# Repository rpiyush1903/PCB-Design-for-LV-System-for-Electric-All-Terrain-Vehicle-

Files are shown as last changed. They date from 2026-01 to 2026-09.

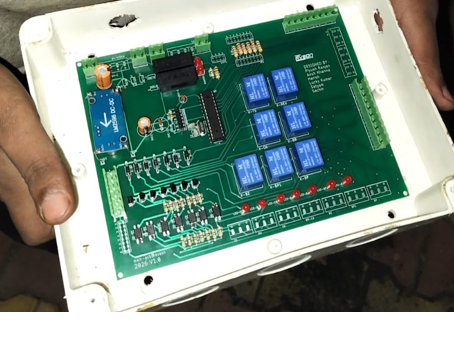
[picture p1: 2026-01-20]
LV-Control-Unit.png

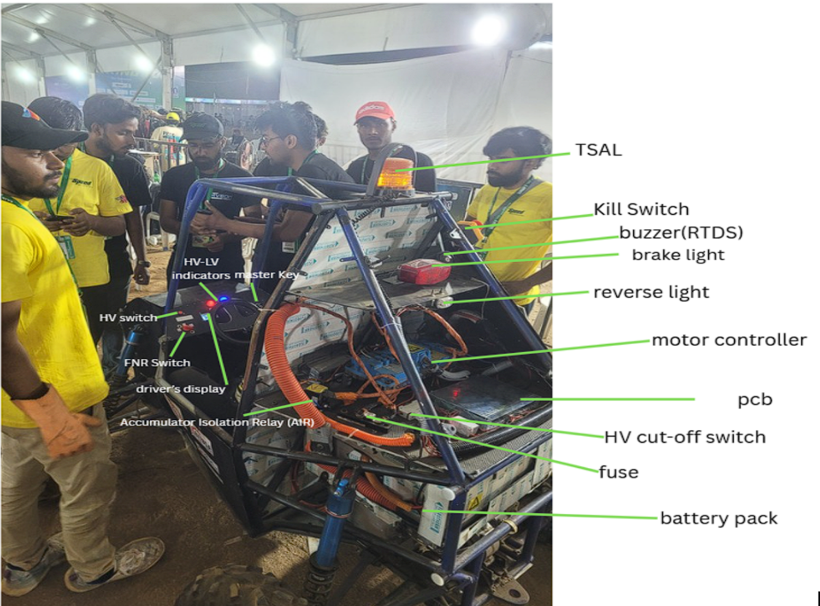
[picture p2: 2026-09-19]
e-atv.png

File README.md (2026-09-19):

# e-ATV Vehicle Control Unit (VCU)

## What this is

This is the Vehicle Control Unit (VCU) for our electric All-Terrain Vehicle, engineered specifically for the demands of e-BAJA SAE competition . The control unit should be resistant to high vibration, rough terrain, electrical noise etc.

The VCU sits at the center of the car's low-voltage control system. It reads every driver input ,ignition Key, cockpit and chassis kill switches, brake pressure switch, accelerator position sensor, and Forward/Neutral/Reverse selection(Rotary Switch) and turns that into safe, Low Voltage control over the high-voltage tractive system. It continuously monitors the safety loop, runs the basic starting and running logic of the vehicle , Controls all the Low Voltage and High Voltage components in the vehicle and is built to shut the whole tractive system down immediately if anything looks wrong.

## Hardware Design & PCB Architecture
The whole electrical layout is built with the idea of Simple , Efficient Control and Robust Safety 

The VCU PCB is made to protect the ATmega328P microcontroller from high-voltage transients, high-current switching noise, and off-road mechanical vibration through strategic domain isolation and multi-stage output driving.

## 1. Power Distribution & System Isolation

### 48V Tractive System
Powers the motor controller through a 160A main fuse, HV cut-off switch, and main Accumulator Isolation Relays (AIRs).

### 12V LV System
Stepped down via a 48V-to-12V DC-DC converter to power external safety loops, lights, RTDS buzzer, and relay coils.

### 5V Logic System
Generated by a dedicated 12V-to-5V buck converter with electrolytic (100 µF) and ceramic (0.1 µF) decoupling capacitors, providing clean power exclusively to the MCU and sensor pull-up networks.

## 2. Optocoupler & Active-LOW Output Drive

### Active-LOW Logic
GPIO output pins require  0V (LOW) signal to energize outputs. Floating pin states during bootloader execution or CPU resets cannot accidentally trigger relays.

### Galvanic Isolation
Output pins drive PC817 optocouplers, creating an optical barrier between the 5V MCU logic ground and the 12V relay ground plane.

### Low-Side Switching
Optocoupler phototransistors trigger BC547 NPN transistors to sink 12V relay coil current, keeping high current draw entirely off the 5V logic rail.

### Flyback Diode Clamping
1N4007 flyback diodes are placed in reversed manner and parallel across all relay coils to safely dissipate back-EMF inductive voltage spikes ($V = -L \frac{di}{dt}$) during de-energization, preventing CMOS latch-up.

### Digital Inputs
Brake pressure switch (A3), FNR selectors (A4/A5), and safety interlocks (A1) utilize pull-down resistor networks and hardware debouncing to guarantee stable state detection across rough terrain.

### Power Distribution

* **High Voltage Rail:** The 48V accumulator feeds through a 160A main fuse and an HV cut-off switch straight to the motor controller.
* **Low Voltage Rail:** A 48V→12V DC-DC converter powers the vehicle's 12V accessories and the dashboard safety loop.
* **Logic Power:** The ATmega328P and its supporting logic get their own dedicated 12V→5V buck converter, kept isolated from everything else on the low-voltage side.

### Core Components

* **MCU:** ATmega328P
* **Sensor Inputs:** Ignition key, cockpit and chassis kill switches, brake pressure switch, accelerator (Hall-effect sensor), and the Forward/Neutral/Reverse selector all fed from the dashboard cluster.
* **Actuator Outputs:** Relay-driven outputs for the TSAL, reverse light, main contactor (accumulator isolation relay), brake light, and the RTDS buzzer.

## Firmware Architecture

The firmware (C++, compiled through Arduino) is built with the starting sequence in mind and safety as a priority .

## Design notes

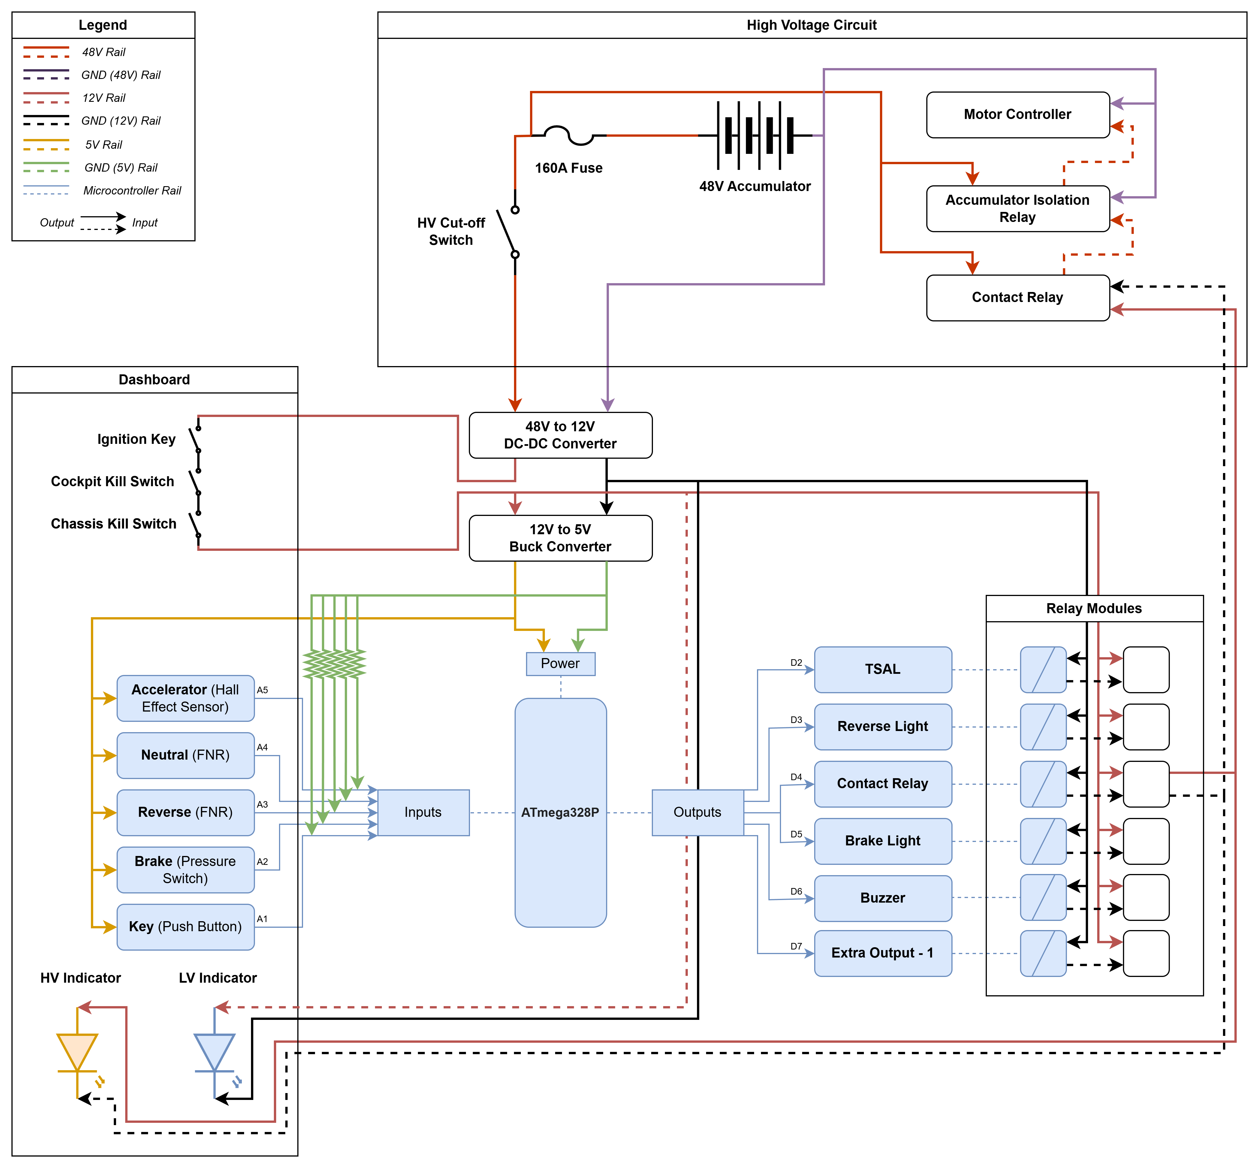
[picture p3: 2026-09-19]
LV-HV-System-Circuit-Diagram.png

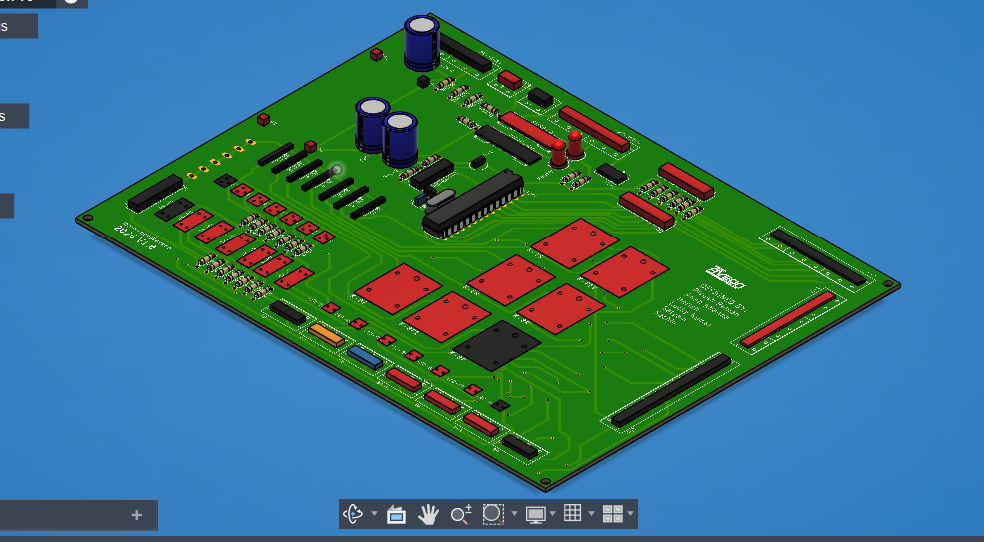
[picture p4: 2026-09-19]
LV-PCB-model.png

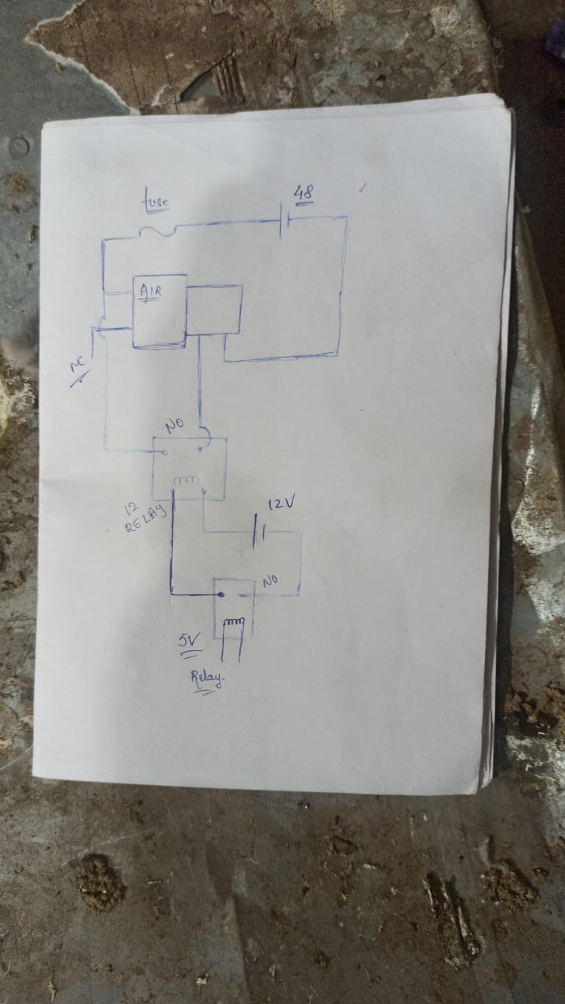
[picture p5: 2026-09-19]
HV-Circuit-Diagram(AIR).jpeg

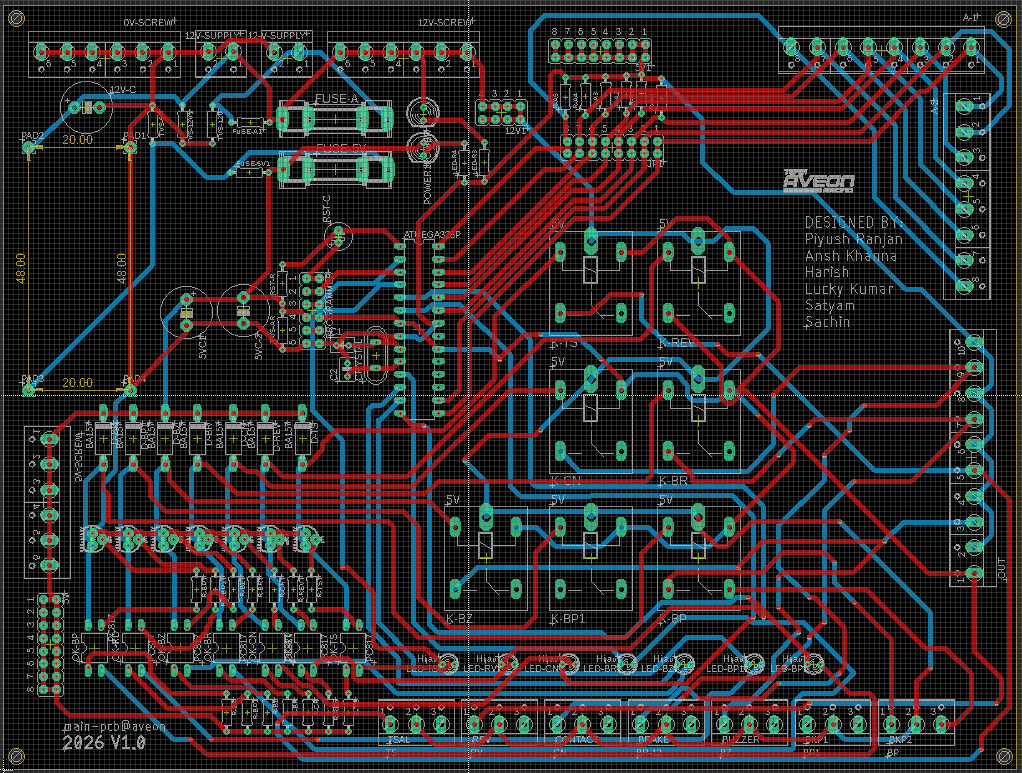
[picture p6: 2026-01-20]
LV-VCU-PCB-brd-file-ss.png

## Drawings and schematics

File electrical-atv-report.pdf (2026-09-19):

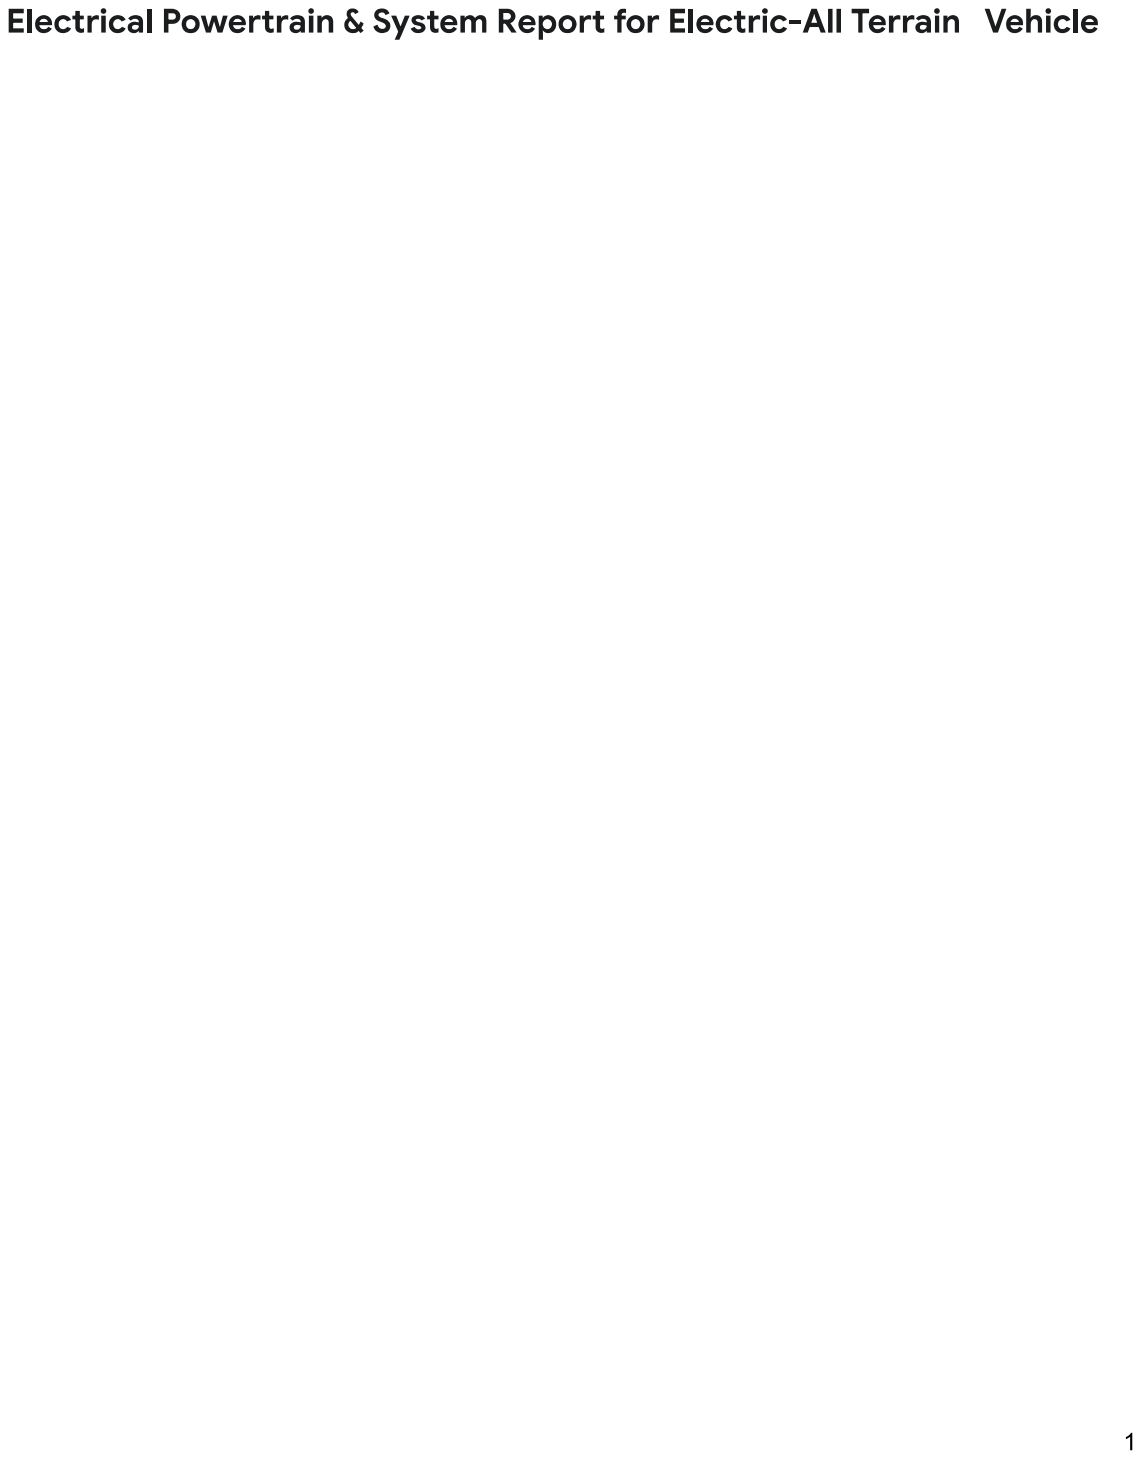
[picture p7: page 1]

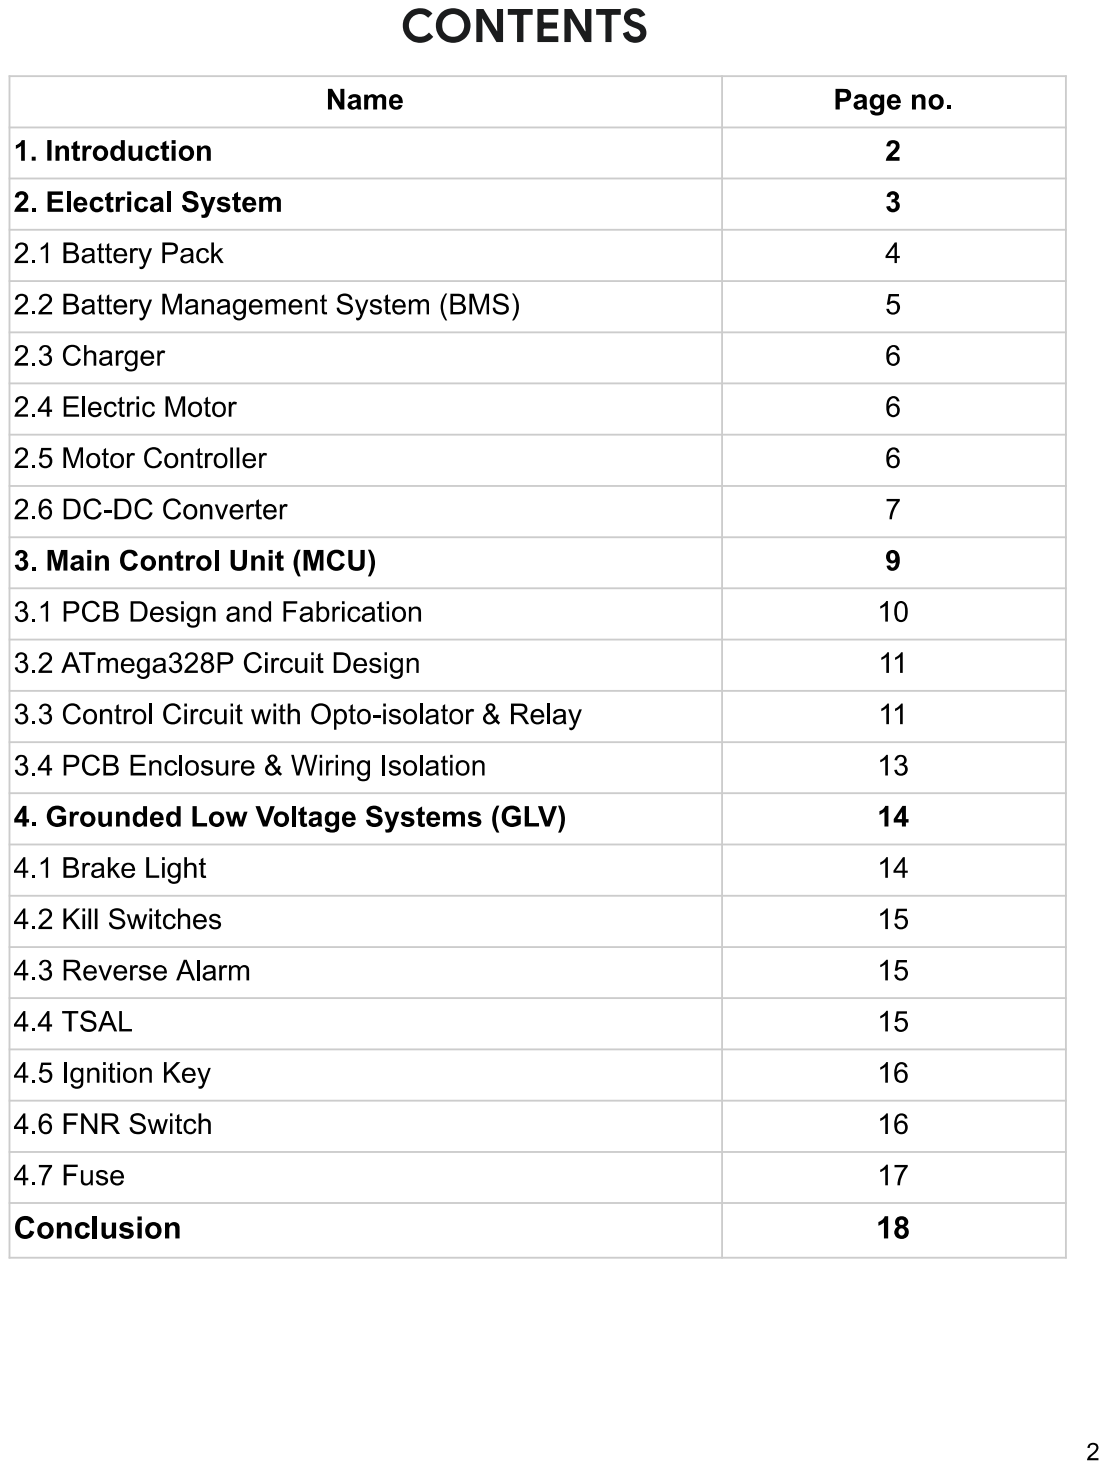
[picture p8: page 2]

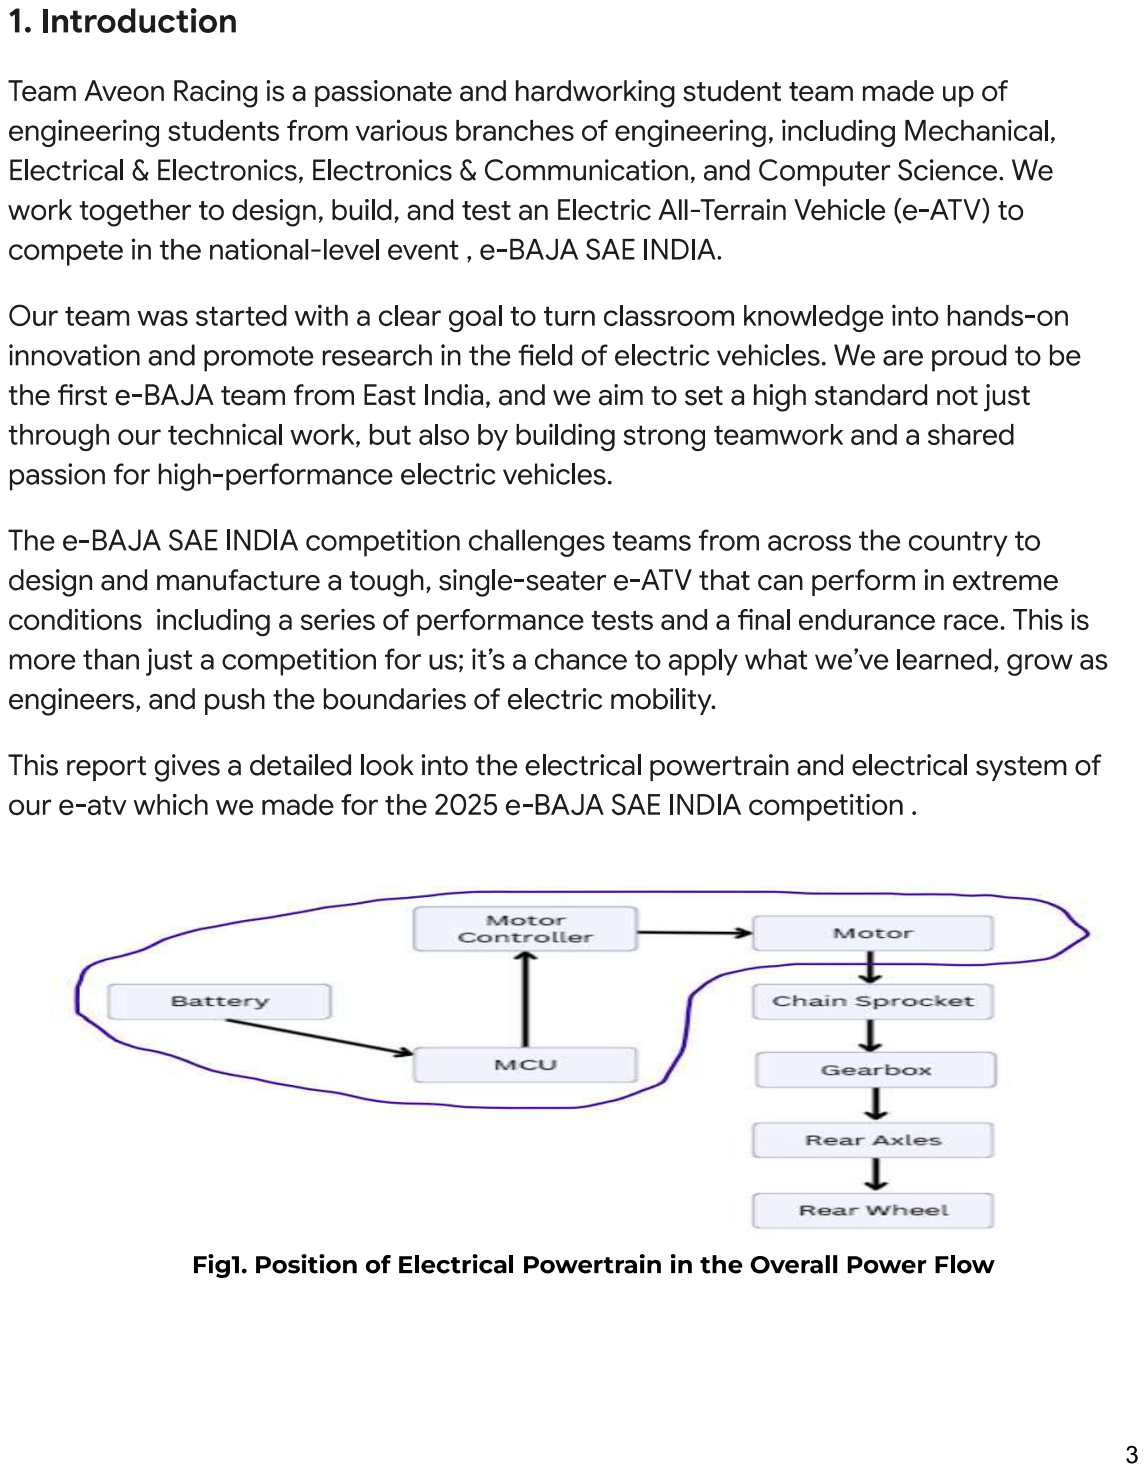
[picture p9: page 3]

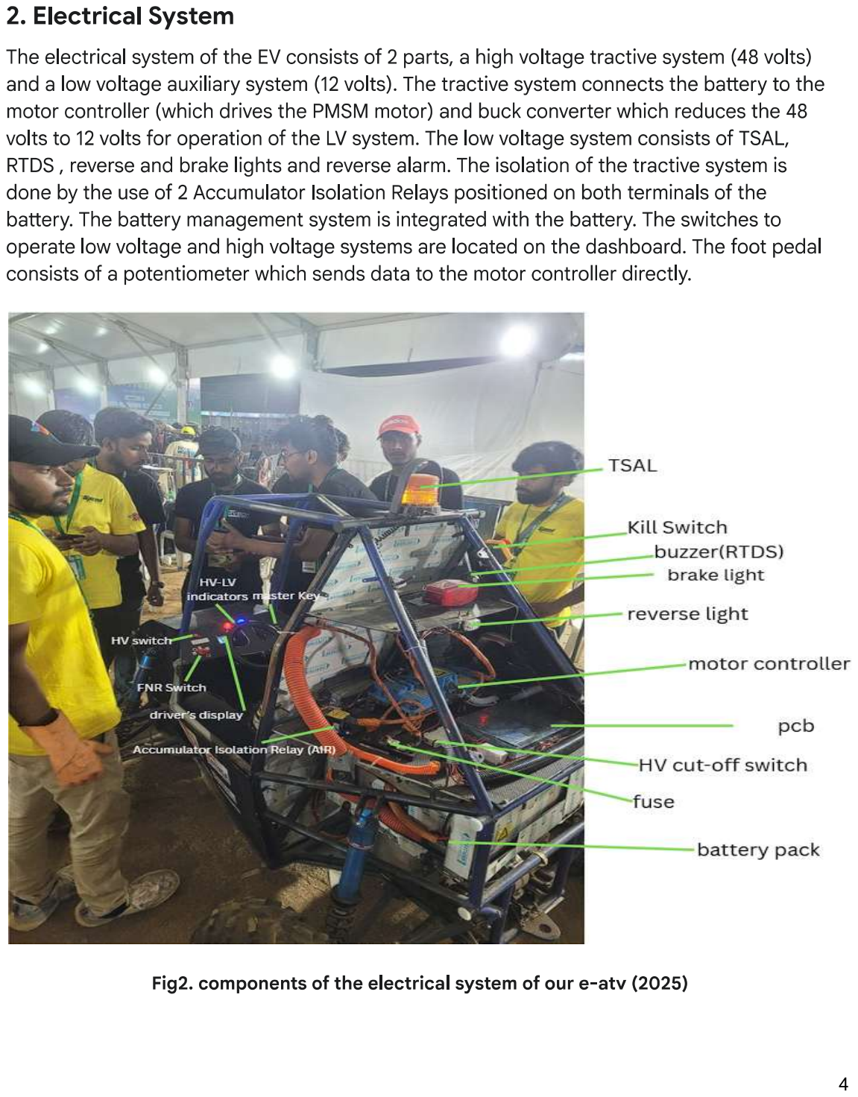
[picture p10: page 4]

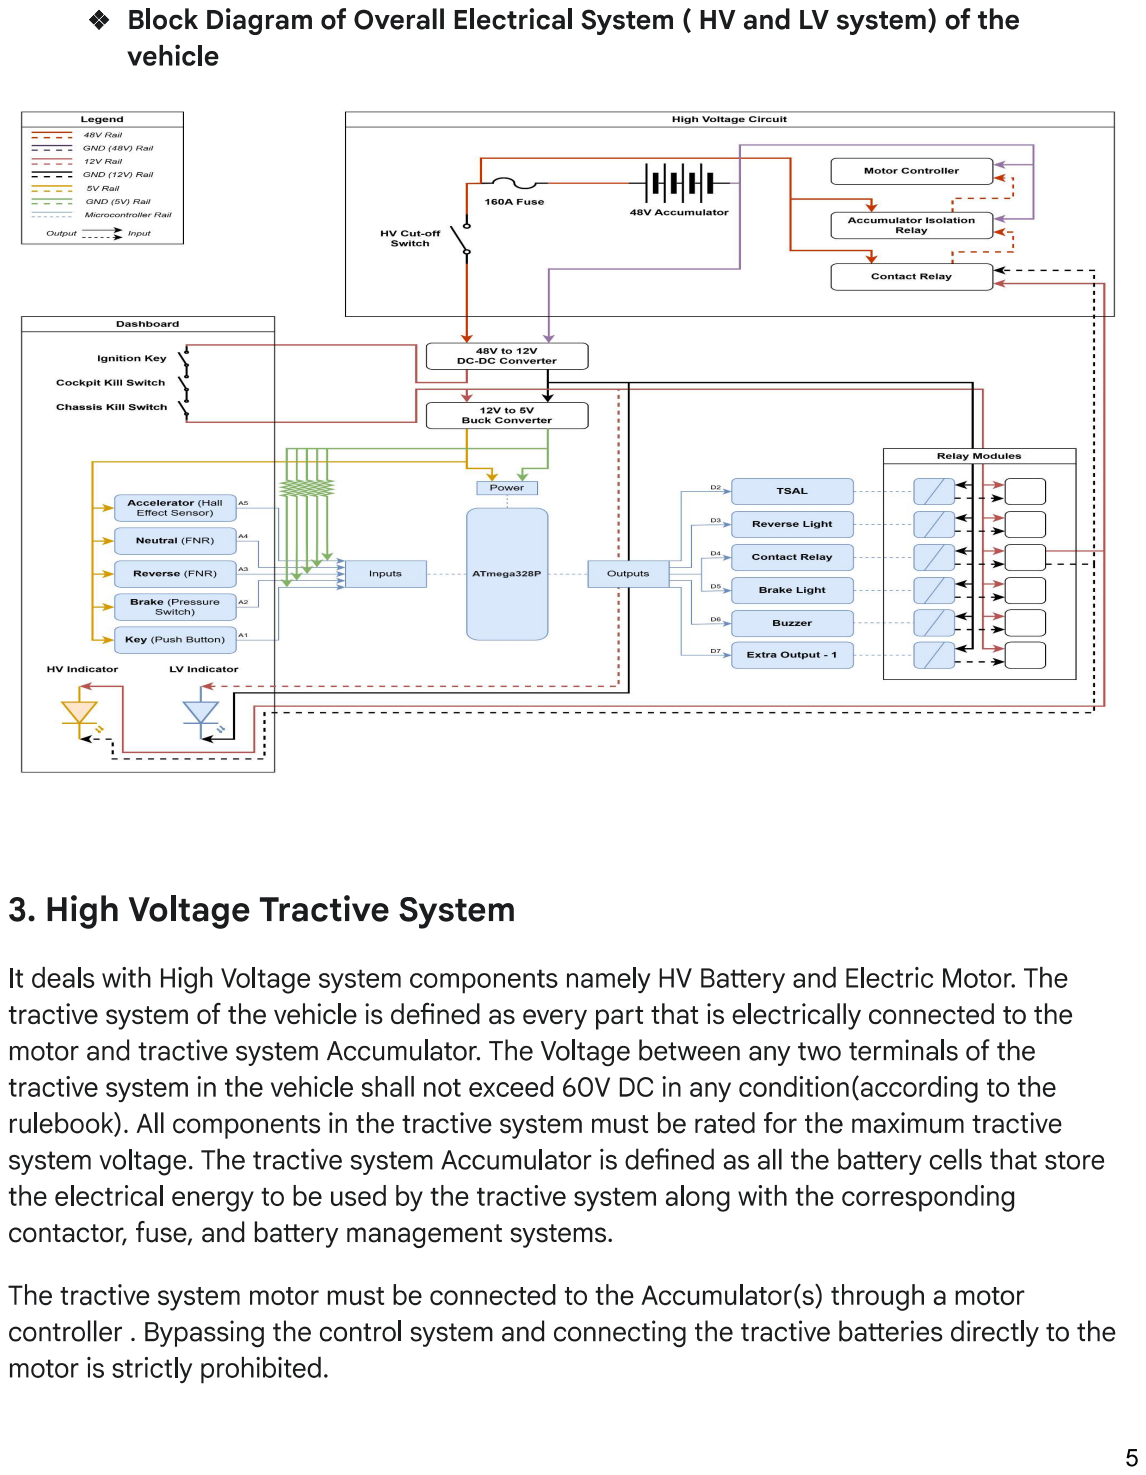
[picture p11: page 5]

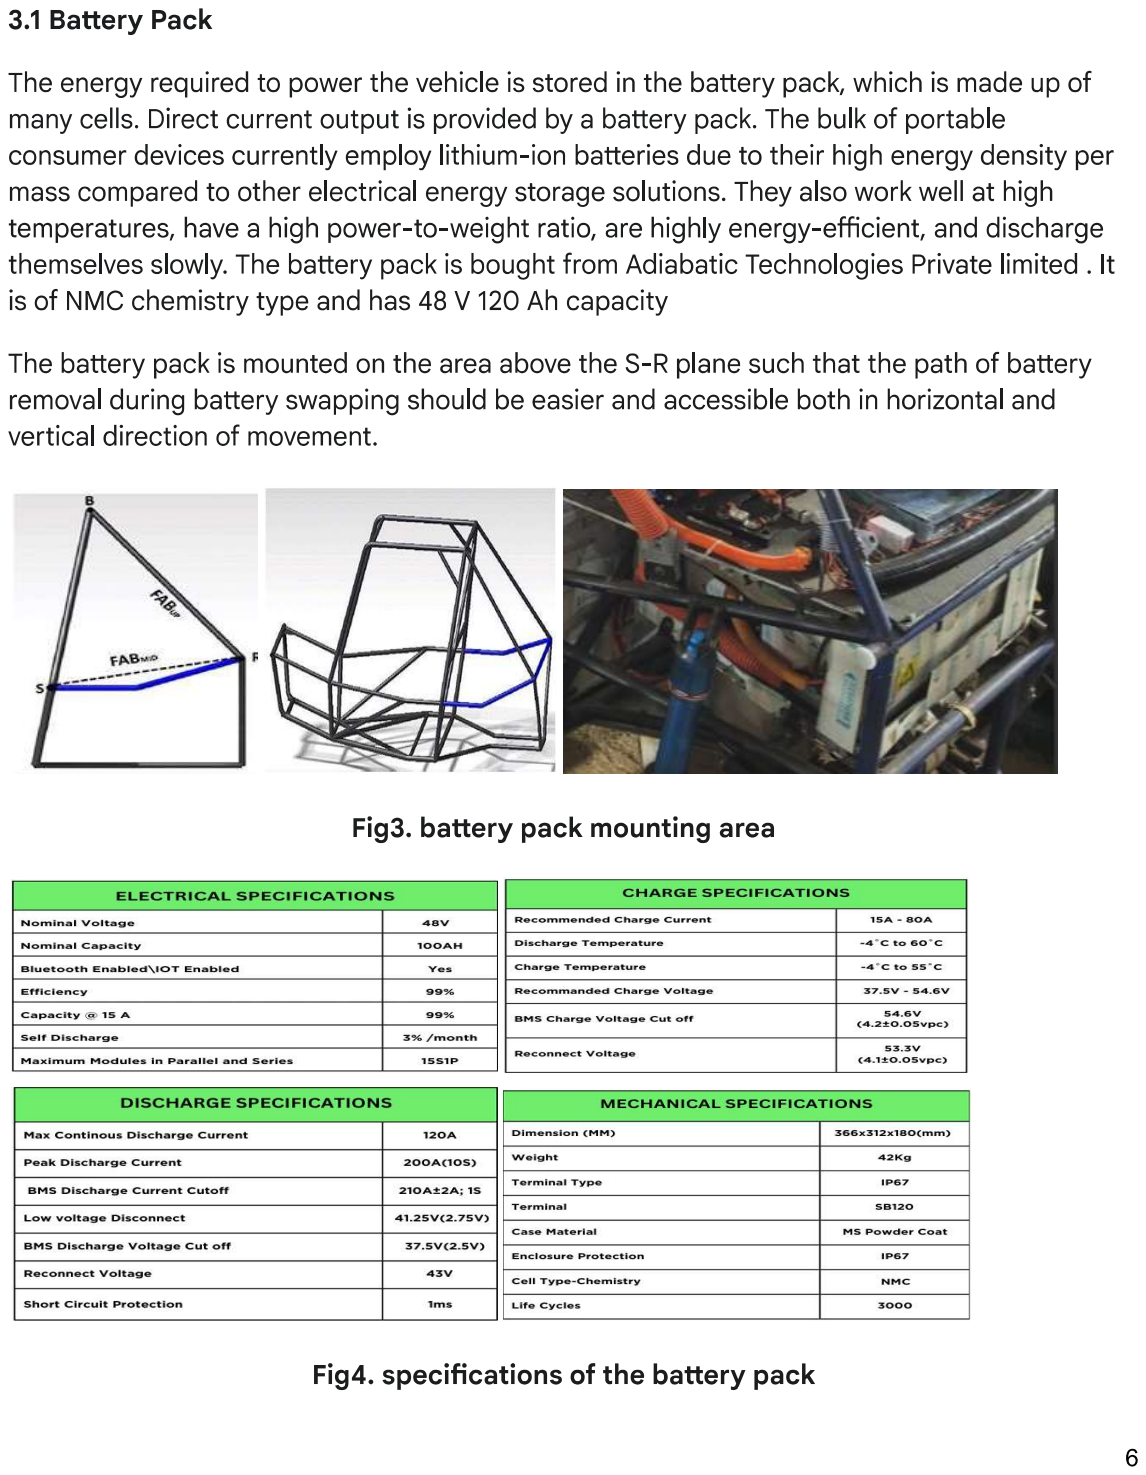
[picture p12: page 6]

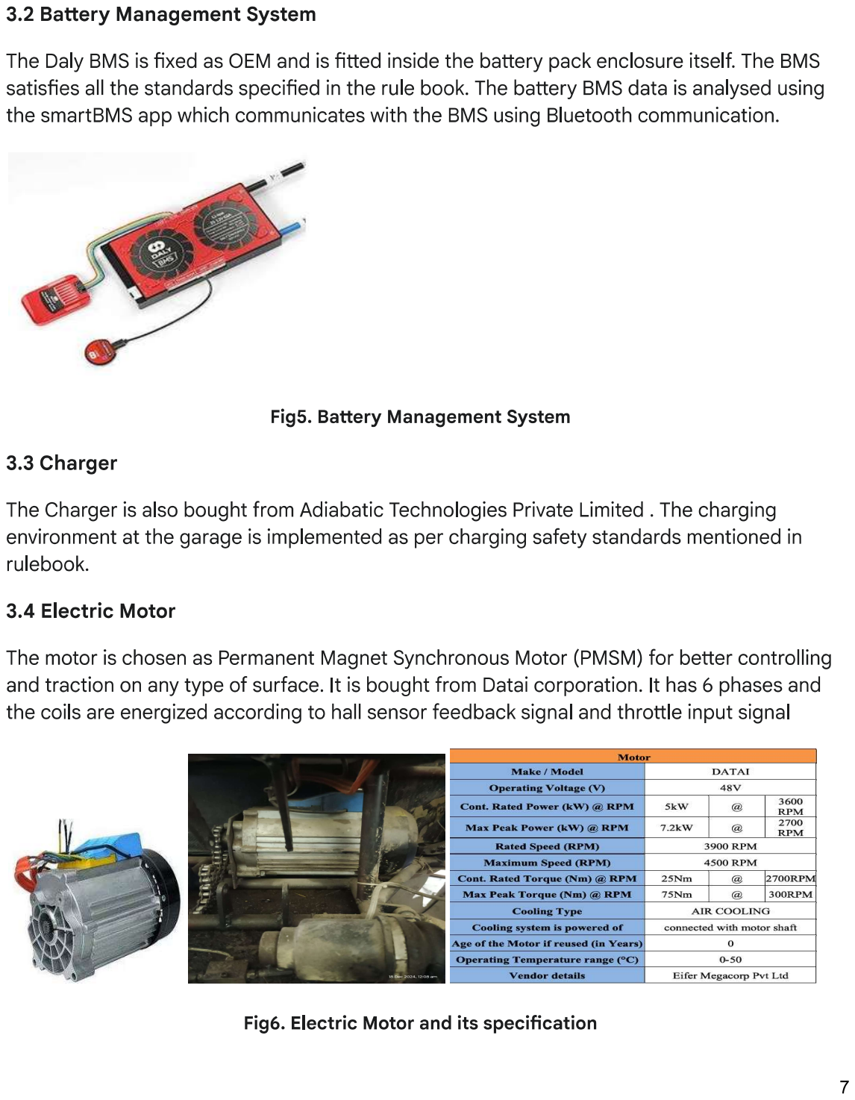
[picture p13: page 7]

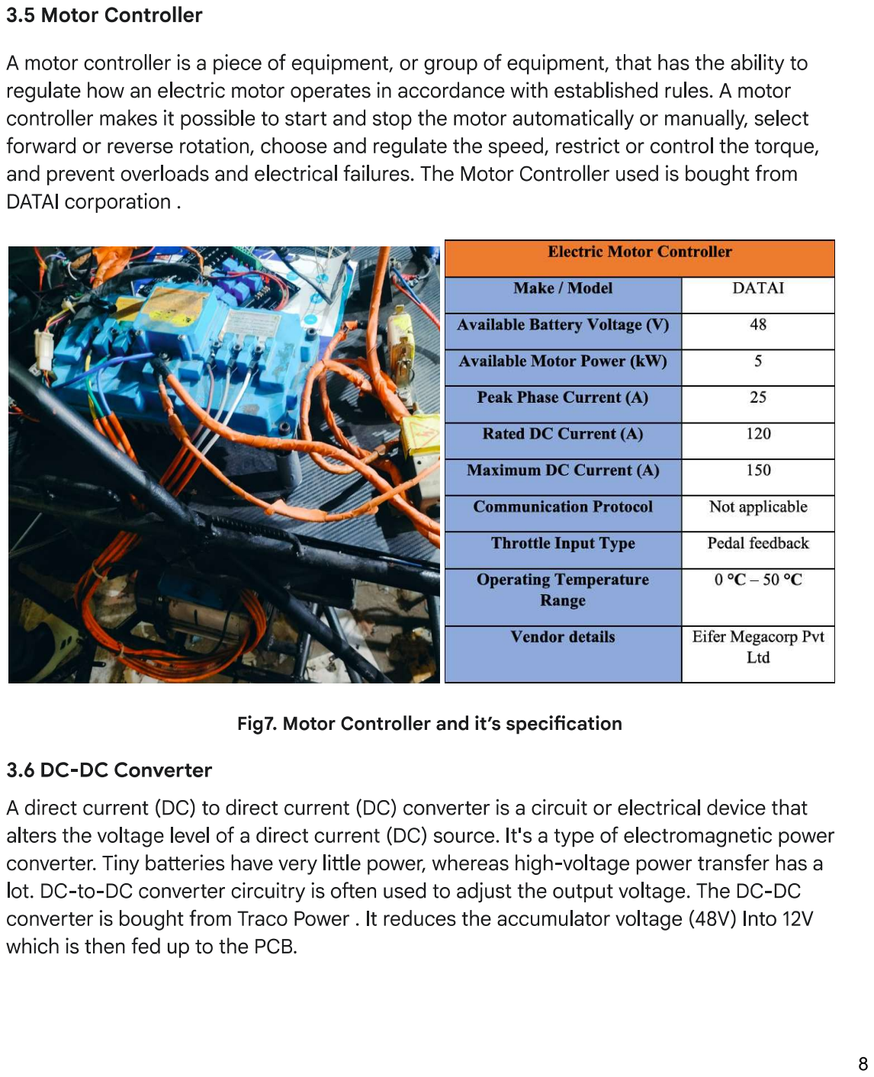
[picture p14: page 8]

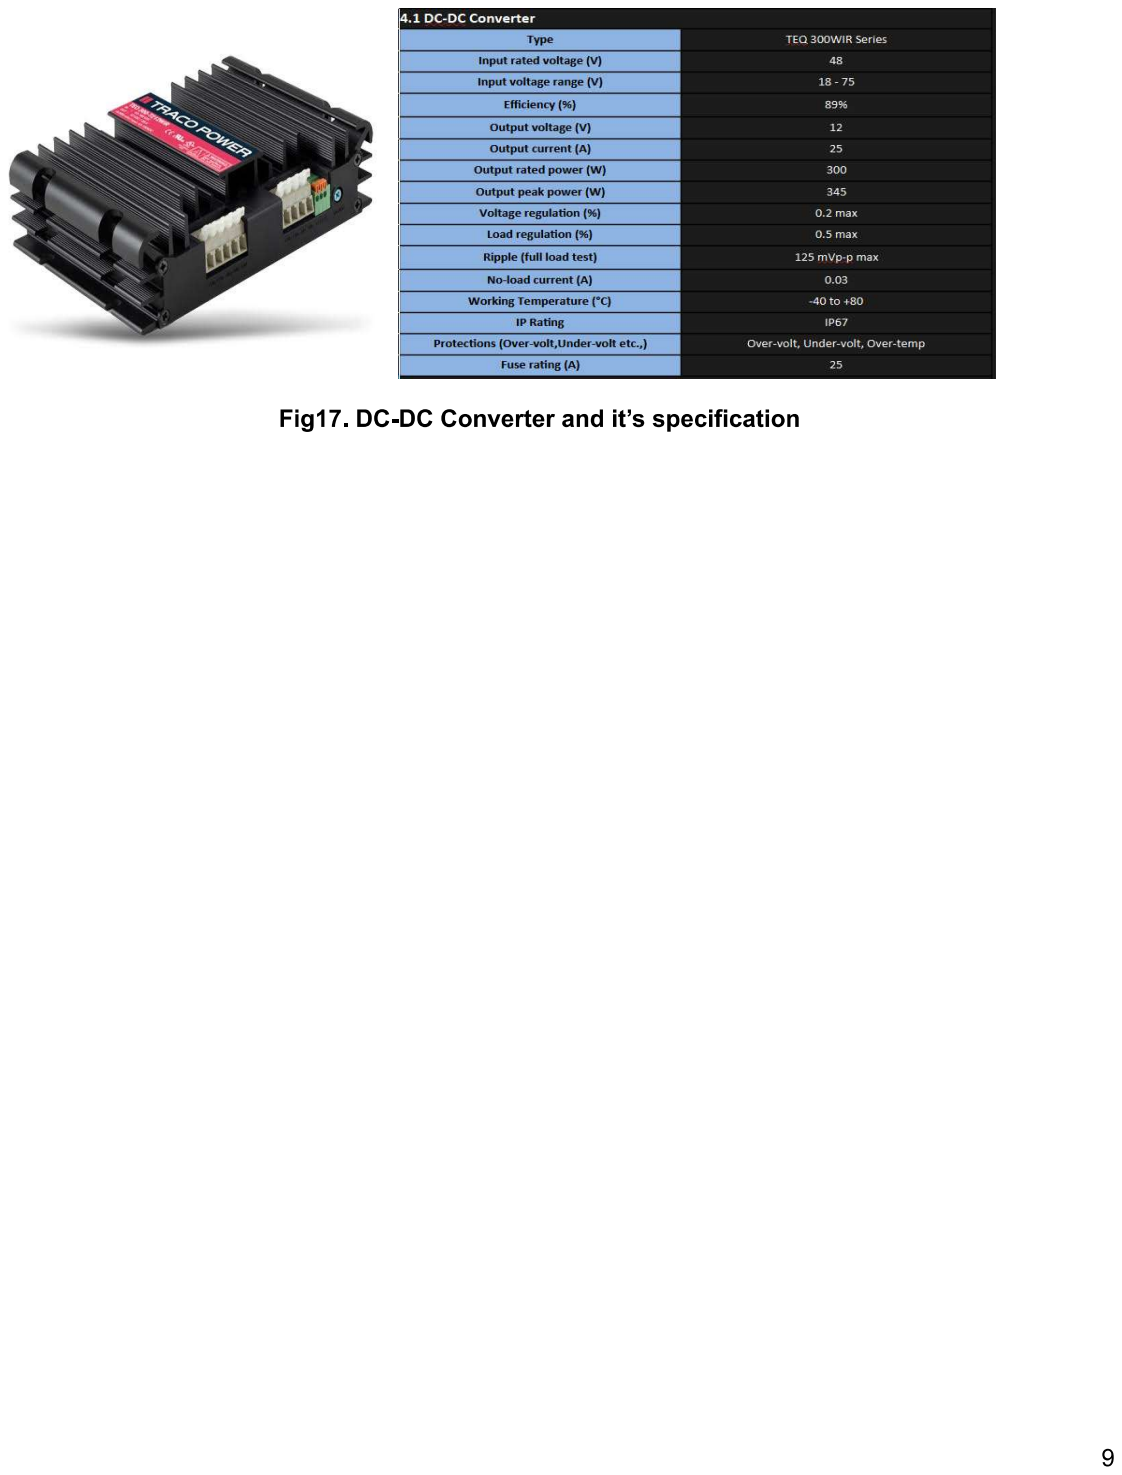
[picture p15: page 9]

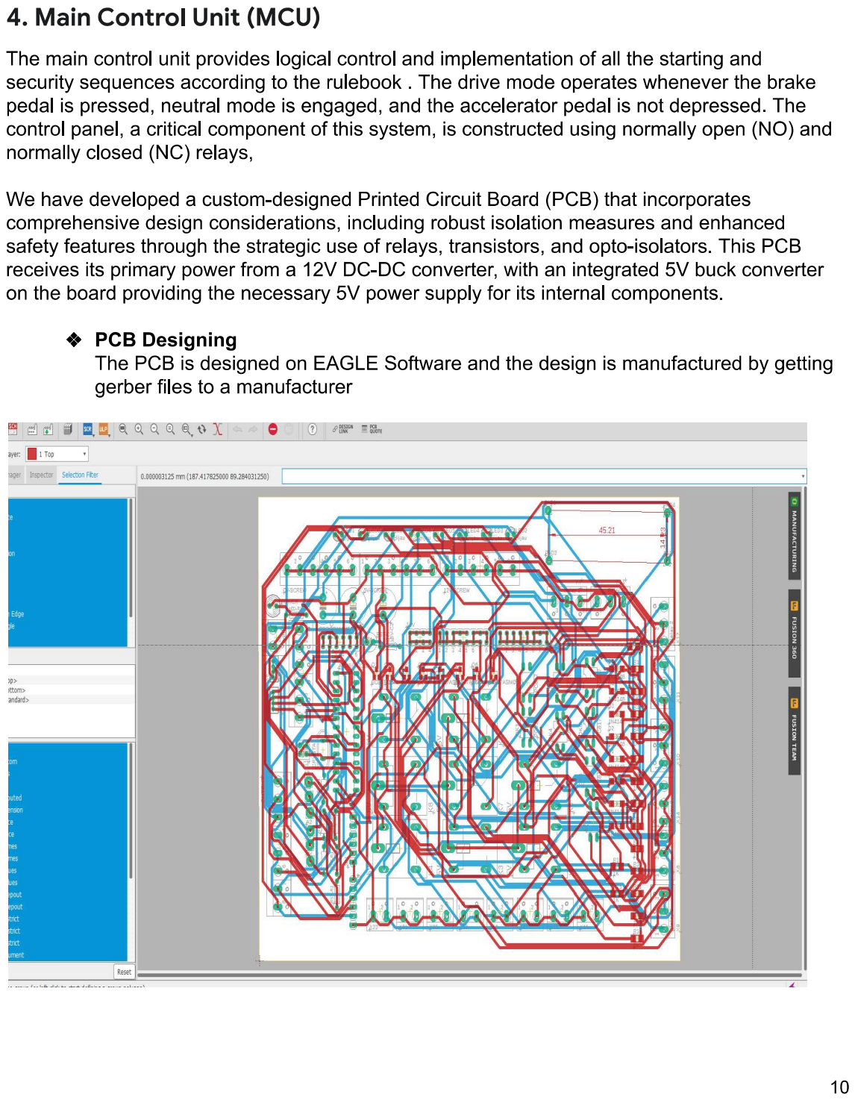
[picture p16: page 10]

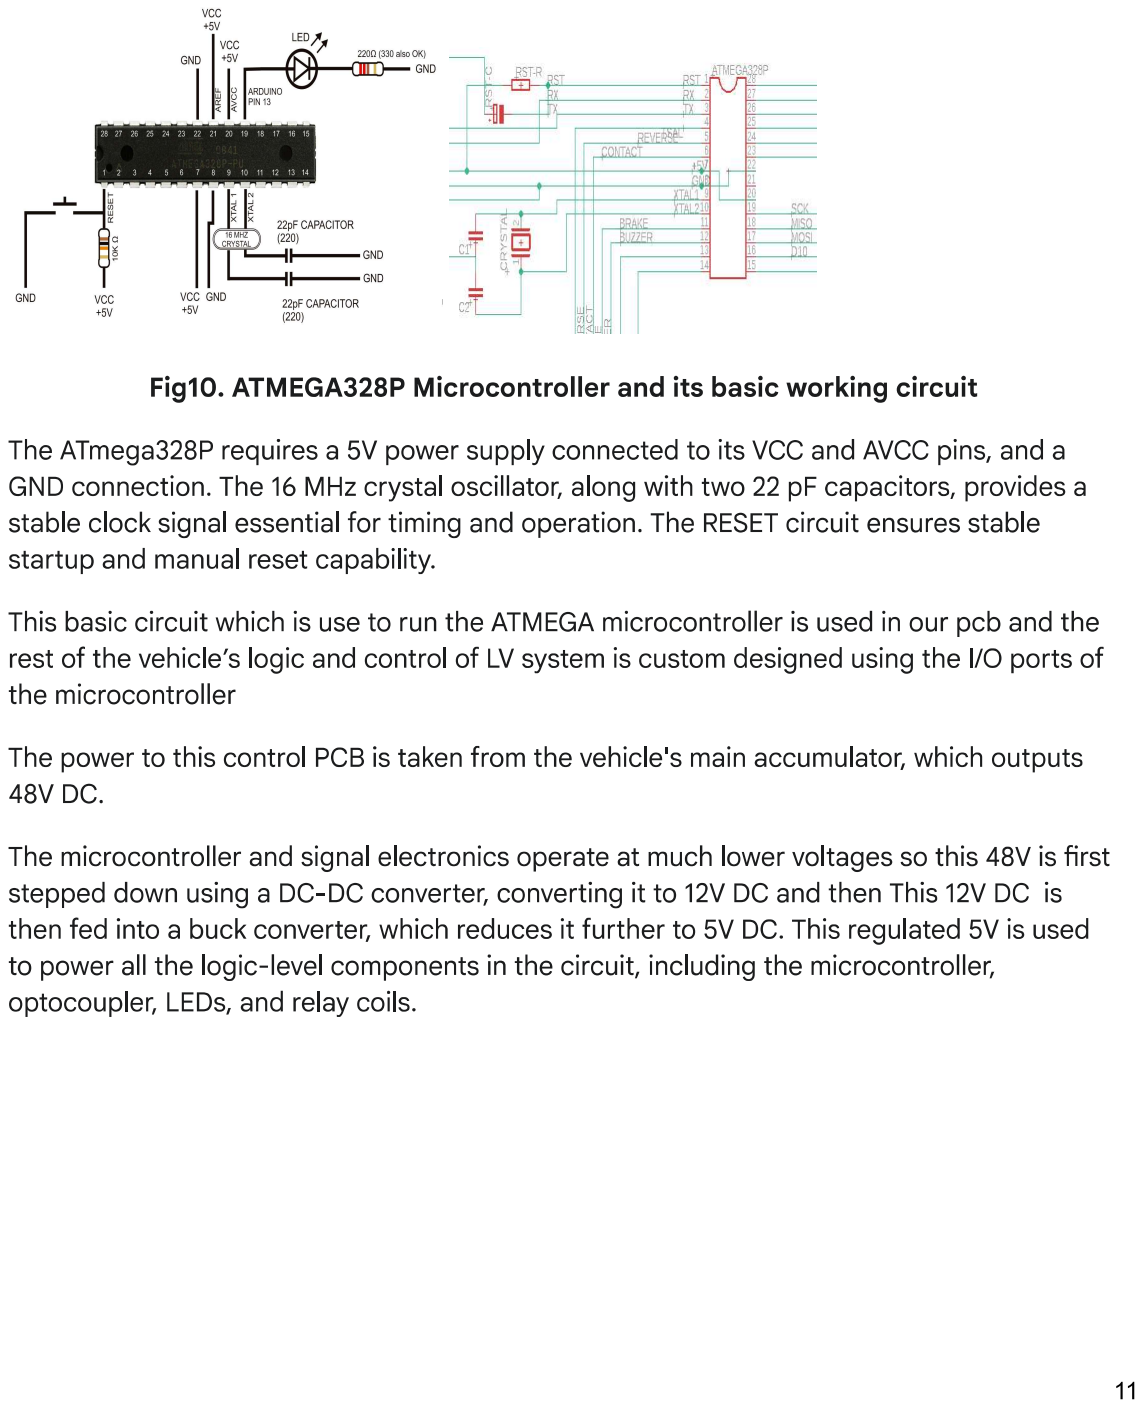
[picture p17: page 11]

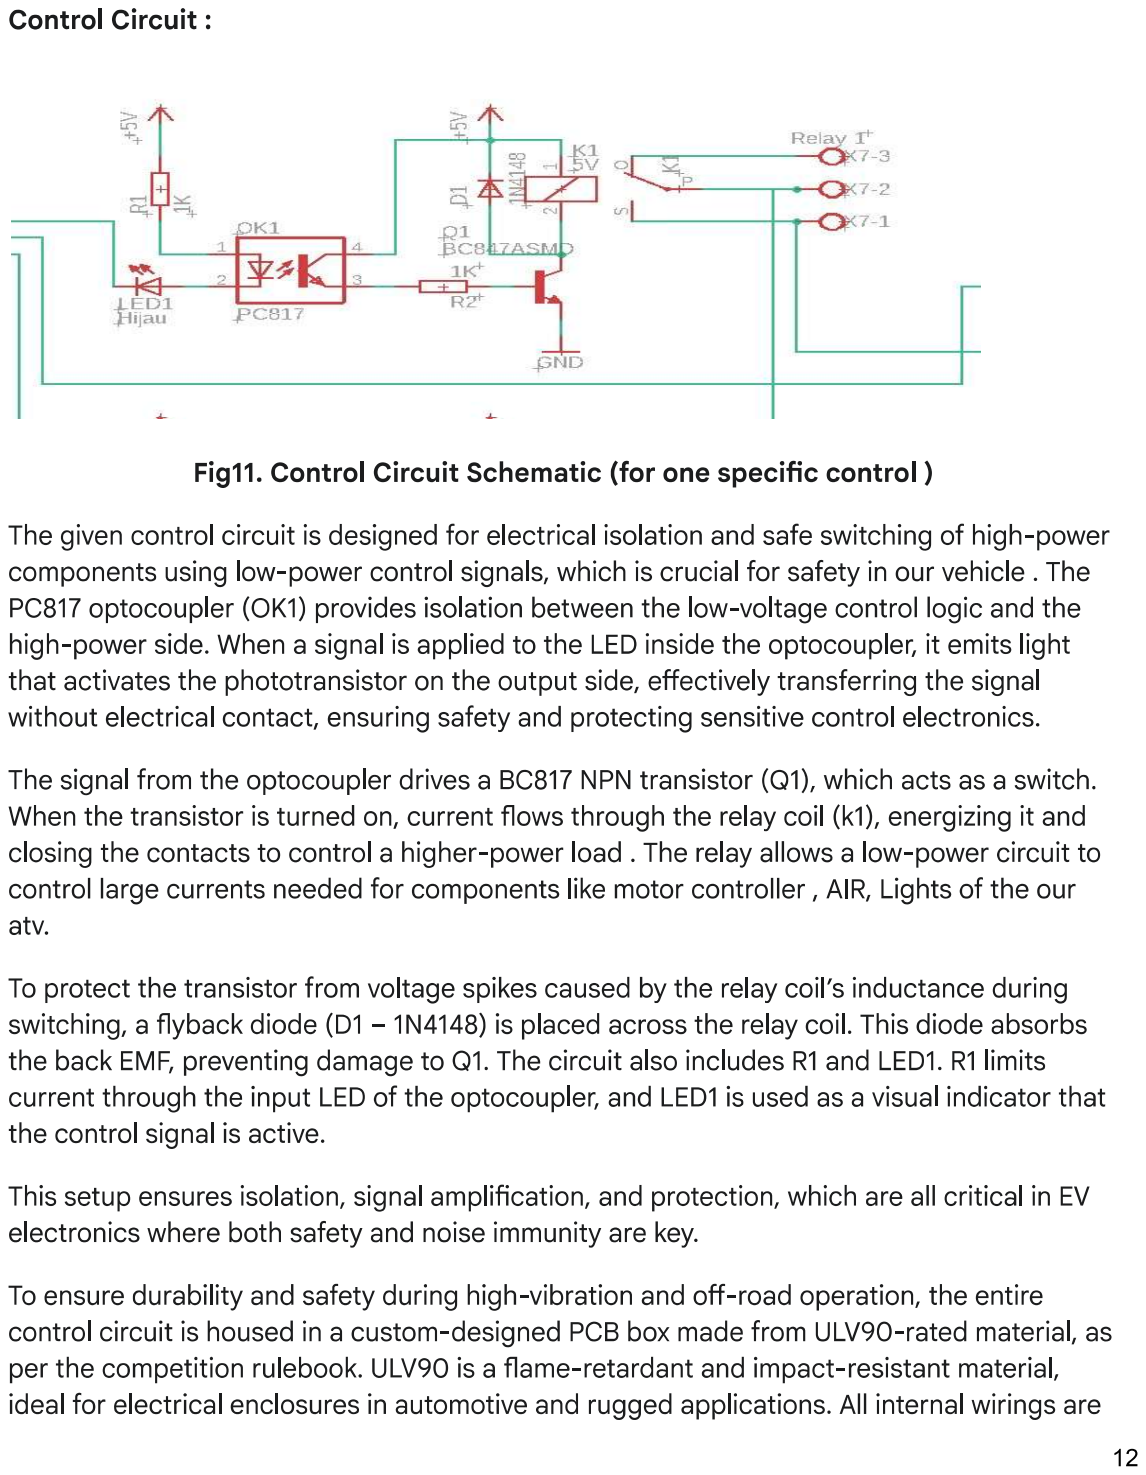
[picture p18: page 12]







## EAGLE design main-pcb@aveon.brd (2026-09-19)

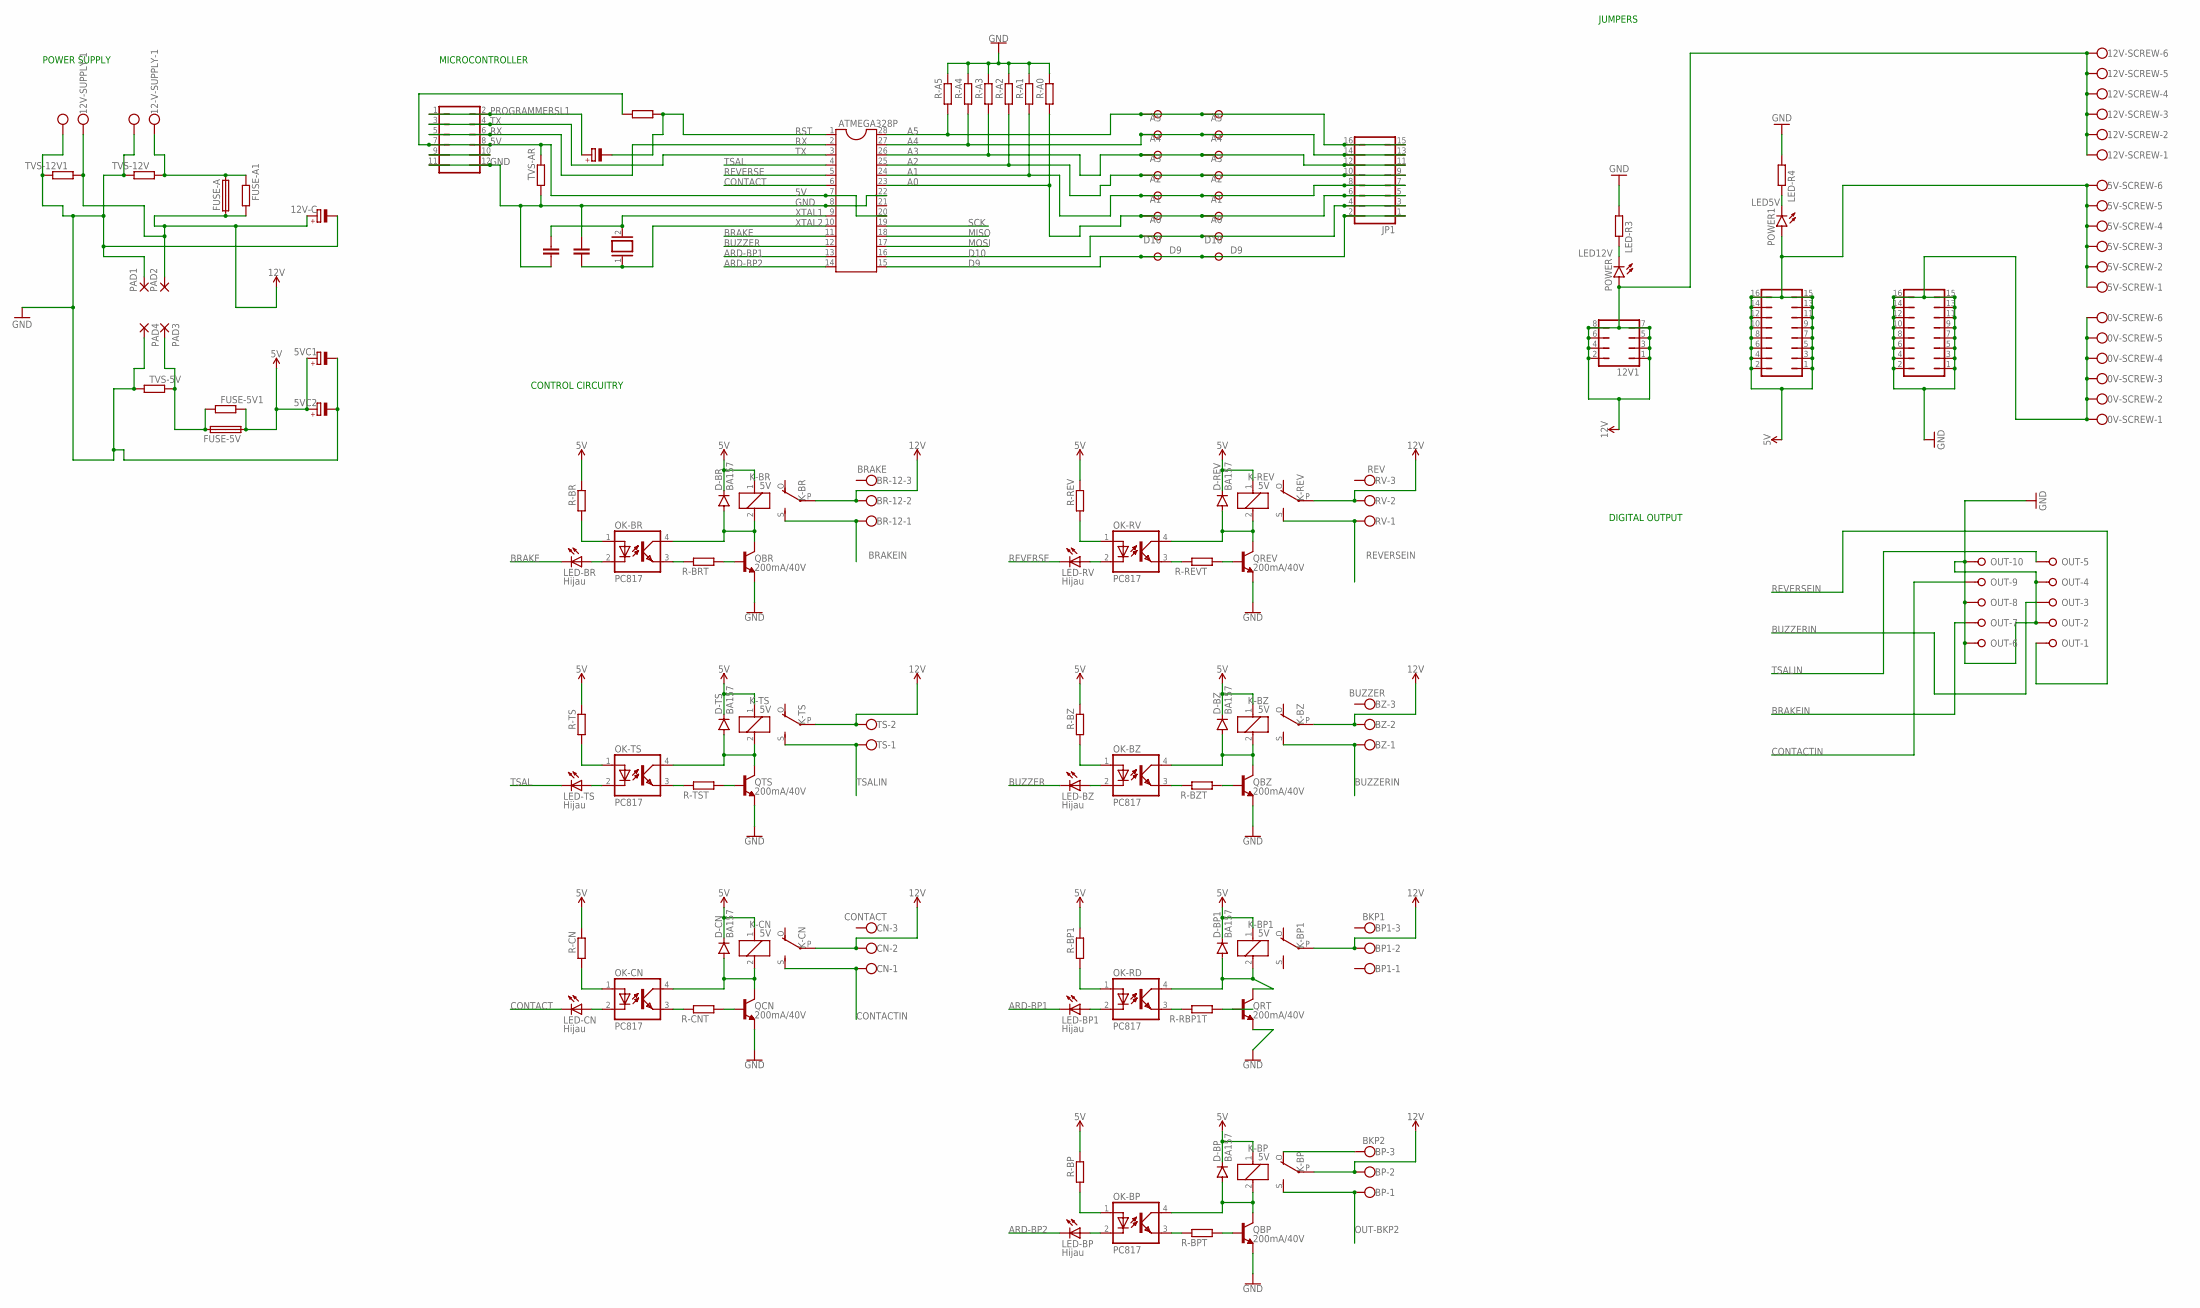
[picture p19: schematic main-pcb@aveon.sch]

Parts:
0V-SCREW, 5V-SCREW, 12V-SCREW: W237-6
5V, 5V1: JP8Q
5VC1, 5VC-2, 12V-C: CPOL-EUE5-10.5; E5-10,5
12-V-SUPPLY, 12V-SUPPLY: W237-102
12V1: JP4Q
A-1, A-2: W237-08P; W237-8P
ATMEGA328P: DIL28-3
BP: BKP2; W237-103
BP1: BKP1; W237-103
BR-12: BRAKE; W237-103
BZ: BUZZER; W237-103
C1, C2: C-EU025-030X050; C025-030X050
CN: CONTACT; W237-103
CRYSTAL: XTAL/S; QS
D-BP, D-BP1: BA157; P1-10
D-BR: BA157; P1-10
D-BZ: BA157; P1-10
D-CN: BA157; P1-10
D-REV: BA157; P1-10
D-TS: BA157; P1-10
FUSE-5V: SHK20L
FUSE-5V1: R-EU_0204/7; 0204/7
FUSE-A: SHK20L
FUSE-A1: R-EU_0204/7; 0204/7
JP1: JP8Q
K-BP, K-BP1: 5V; ZF112
K-BR: 5V; ZF112
K-BZ: 5V; ZF112
K-CN: 5V; ZF112
K-REV: 5V; ZF112
K-TS: 5V; ZF112
LED-BP, LED-BP1: Hijau; LED3MM
LED-BR: Hijau; LED3MM
LED-BZ: Hijau; LED3MM
LED-CN: Hijau; LED3MM
LED-R3, LED-R4: R-EU_0204/7; 0204/7
LED-RV: Hijau; LED3MM
LED-TS: Hijau; LED3MM
OK-BP: PC817; DIL04
OK-BR: PC817; DIL04
OK-BZ: PC817; DIL04
OK-CN: PC817; DIL04
OK-RD: PC817; DIL04
OK-RV: PC817; DIL04
OK-TS: PC817; DIL04
OUT: W237-10P
PAD1, PAD2, PAD3, PAD4: 2,54/1,1
POWER, POWER1: LED5MM
PROGRAMMER: JP6Q
QBP: 200mA/40V; TO-92
QBR: 200mA/40V; TO-92
QBZ: 200mA/40V; TO-92
QCN: 200mA/40V; TO-92
QREV: 200mA/40V; TO-92
QRT: 200mA/40V; TO-92
QTS: 200mA/40V; TO-92
R-A0, R-A1, R-A2, R-A3, R-A4, R-A5: R-EU_0204/7; 0204/7
R-BP, R-BP1: R-EU_0204/7; 0204/7
R-BPT: R-EU_0204/7; 0204/7
R-BR: R-EU_0204/7; 0204/7
R-BRT: R-EU_0204/7; 0204/7
R-BZ: R-EU_0204/7; 0204/7
R-BZT: R-EU_0204/7; 0204/7
R-CN: R-EU_0204/7; 0204/7
R-CNT: R-EU_0204/7; 0204/7
R-RBP1T: R-EU_0204/7; 0204/7
R-REV: R-EU_0204/7; 0204/7
R-REVT: R-EU_0204/7; 0204/7
R-TS: R-EU_0204/7; 0204/7
R-TST: R-EU_0204/7; 0204/7
RST-C: CPOL-EUE2.5-6; E2,5-6
RST-R: R-EU_0204/7; 0204/7
RV: REV; W237-103
TS: TSAL; W237-103
TVS-5V, TVS-12V, TVS-12V1: R-EU_0204/7; 0204/7
TVS-AR: R-EU_0204/7; 0204/7

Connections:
5V: 5V.1, 5V.2, 5V.3, 5V.4, 5V.5, 5V.6, 5V.7, 5V.8, 5V.9, 5V.10, 5V.11, 5V.12, 5V.13, 5V.14, 5V.15, 5V.16, 5V-SCREW.1, 5V-SCREW.2, 5V-SCREW.3, 5V-SCREW.4, 5V-SCREW.5, 5V-SCREW.6, 5VC1.+, 5VC-2.+, ATMEGA328P.7, ATMEGA328P.20, D-BP.C, D-BP1.C, D-BR.C, D-BZ.C, D-CN.C, D-REV.C, D-TS.C, FUSE-5V.1A, FUSE-5V1.2, K-BP.1, K-BP1.1, K-BR.1, K-BZ.1, K-CN.1, K-REV.1, K-TS.1, POWER1.A, PROGRAMMER.7, PROGRAMMER.8, R-BP.2, R-BP1.2, R-BR.2, R-BZ.2, R-CN.2, R-REV.2, R-TS.2, RST-R.1, TVS-AR.2
12V: 12V1.1, 12V1.2, 12V1.3, 12V1.4, 12V1.5, 12V1.6, 12V1.7, 12V1.8, 12V-C.+, 12V-SCREW.1, 12V-SCREW.2, 12V-SCREW.3, 12V-SCREW.4, 12V-SCREW.5, 12V-SCREW.6, 12V-SUPPLY.1, BP.2, BP1.2, BR-12.2, BZ.2, CN.2, FUSE-A.1A, FUSE-A1.1, K-BP.P, K-BP1.P, K-BR.P, K-BZ.P, K-CN.P, K-REV.P, K-TS.P, PAD2.1, POWER.A, RV.2, TS.2, TVS-12V1.1
A0: A-1.3, A-2.3, ATMEGA328P.23, JP1.5, JP1.6, R-A0.1
A1: A-1.4, A-2.4, ATMEGA328P.24, JP1.7, JP1.8, R-A1.1
A2: A-1.5, A-2.5, ATMEGA328P.25, JP1.9, JP1.10, R-A2.1
A3: A-1.6, A-2.6, ATMEGA328P.26, JP1.11, JP1.12, R-A3.1
A4: A-1.7, A-2.7, ATMEGA328P.27, JP1.13, JP1.14, R-A4.1
A5: A-1.8, A-2.8, ATMEGA328P.28, JP1.15, JP1.16, R-A5.1
ARD-BP1: ATMEGA328P.13, LED-BP1.K (C)
ARD-BP2: ATMEGA328P.14, LED-BP.K (C)
BRAKE: ATMEGA328P.11, LED-BR.K (C)
BRAKEIN: BR-12.1, K-BR.S, OUT.7
BUZZER: ATMEGA328P.12, LED-BZ.K (C)
BUZZERIN: BZ.1, K-BZ.S, OUT.3
CONTACT: ATMEGA328P.6, LED-CN.K (C)
CONTACTIN: CN.1, K-CN.S, OUT.9
D9: A-1.1, A-2.1, ATMEGA328P.15, JP1.1, JP1.2
D10: A-1.2, A-2.2, ATMEGA328P.16, JP1.3, JP1.4
GND: 0V-SCREW.1, 0V-SCREW.2, 0V-SCREW.3, 0V-SCREW.4, 0V-SCREW.5, 0V-SCREW.6, 5V1.1, 5V1.2, 5V1.3, 5V1.4, 5V1.5, 5V1.6, 5V1.7, 5V1.8, 5V1.9, 5V1.10, 5V1.11, 5V1.12, 5V1.13, 5V1.14, 5V1.15, 5V1.16, 5VC1.-, 5VC-2.-, 12-V-SUPPLY.2, 12V-C.-, 12V-SUPPLY.2, ATMEGA328P.8, ATMEGA328P.22, C1.1, C2.2, LED-R3.1, LED-R4.1, OUT.2, OUT.4, OUT.6, OUT.8, OUT.10, PAD1.1, PAD4.1, PROGRAMMER.11, PROGRAMMER.12, QBP.1 (E), QBR.1 (E), QBZ.1 (E), QCN.1 (E), QREV.1 (E), QRT.1 (E), QTS.1 (E), R-A0.2, R-A1.2, R-A2.2, R-A3.2, R-A4.2, R-A5.2, TVS-5V.1, TVS-12V.2, TVS-12V1.2, TVS-AR.1
LED5V: LED-R4.2, POWER1.K (C)
LED12V: LED-R3.2, POWER.K (C)
MISO: ATMEGA328P.18
MOSI: ATMEGA328P.17
unnamed: 12-V-SUPPLY.1, FUSE-A.2A, FUSE-A1.2, TVS-12V.1
unnamed: OK-BR.1 (A), R-BR.1
unnamed: FUSE-5V.2A, FUSE-5V1.1, PAD3.1, TVS-5V.2
unnamed: OK-RV.1 (A), R-REV.1
unnamed: LED-RV.A, OK-RV.2 (C)
unnamed: LED-BR.A, OK-BR.2 (C)
unnamed: OK-BR.3 (EMIT), R-BRT.2
unnamed: D-BR.A, K-BR.2, OK-BR.4 (COL), QBR.3 (C)
unnamed: QBR.2 (B), R-BRT.1
unnamed: OK-TS.1 (A), R-TS.1
unnamed: LED-TS.A, OK-TS.2 (C)
unnamed: OK-TS.3 (EMIT), R-TST.2
unnamed: QTS.2 (B), R-TST.1
unnamed: D-TS.A, K-TS.2, OK-TS.4 (COL), QTS.3 (C)
unnamed: OK-RV.3 (EMIT), R-REVT.2
unnamed: QREV.2 (B), R-REVT.1
unnamed: D-REV.A, K-REV.2, OK-RV.4 (COL), QREV.3 (C)
unnamed: OK-BZ.1 (A), R-BZ.1
unnamed: LED-BZ.A, OK-BZ.2 (C)
unnamed: OK-BZ.3 (EMIT), R-BZT.2
unnamed: QBZ.2 (B), R-BZT.1
unnamed: D-BZ.A, K-BZ.2, OK-BZ.4 (COL), QBZ.3 (C)
unnamed: OK-CN.1 (A), R-CN.1
unnamed: LED-CN.A, OK-CN.2 (C)
unnamed: OK-CN.3 (EMIT), R-CNT.2
unnamed: QCN.2 (B), R-CNT.1
unnamed: D-CN.A, K-CN.2, OK-CN.4 (COL), QCN.3 (C)
unnamed: OK-RD.1 (A), R-BP1.1
unnamed: LED-BP1.A, OK-RD.2 (C)
unnamed: OK-RD.3 (EMIT), R-RBP1T.2
unnamed: QRT.2 (B), R-RBP1T.1
unnamed: D-BP1.A, K-BP1.2, OK-RD.4 (COL), QRT.3 (C)
unnamed: OK-BP.1 (A), R-BP.1
unnamed: LED-BP.A, OK-BP.2 (C)
unnamed: OK-BP.3 (EMIT), R-BPT.2
unnamed: QBP.2 (B), R-BPT.1
unnamed: D-BP.A, K-BP.2, OK-BP.4 (COL), QBP.3 (C)
unnamed: PROGRAMMER.9, PROGRAMMER.10
unnamed: BP.3, K-BP.O
OUT-BKP2: BP.1, K-BP.S
PROGRAMMERSL1: PROGRAMMER.1, PROGRAMMER.2, RST-C.+
REVERSE: ATMEGA328P.5, LED-RV.K (C)
REVERSEIN: K-REV.S, OUT.1, RV.1
RST: ATMEGA328P.1, RST-C.-, RST-R.2
RX: ATMEGA328P.2, PROGRAMMER.5, PROGRAMMER.6
SCK: ATMEGA328P.19
TSAL: ATMEGA328P.4, LED-TS.K (C)
TSALIN: K-TS.S, OUT.5, TS.1
TX: ATMEGA328P.3, PROGRAMMER.3, PROGRAMMER.4
XTAL1: ATMEGA328P.9, C1.2, CRYSTAL.2
XTAL2: ATMEGA328P.10, C2.1, CRYSTAL.1

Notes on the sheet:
POWER SUPPLY
MICROCONTROLLER
CONTROL CIRCUITRY
JUMPERS
DIGITAL OUTPUT

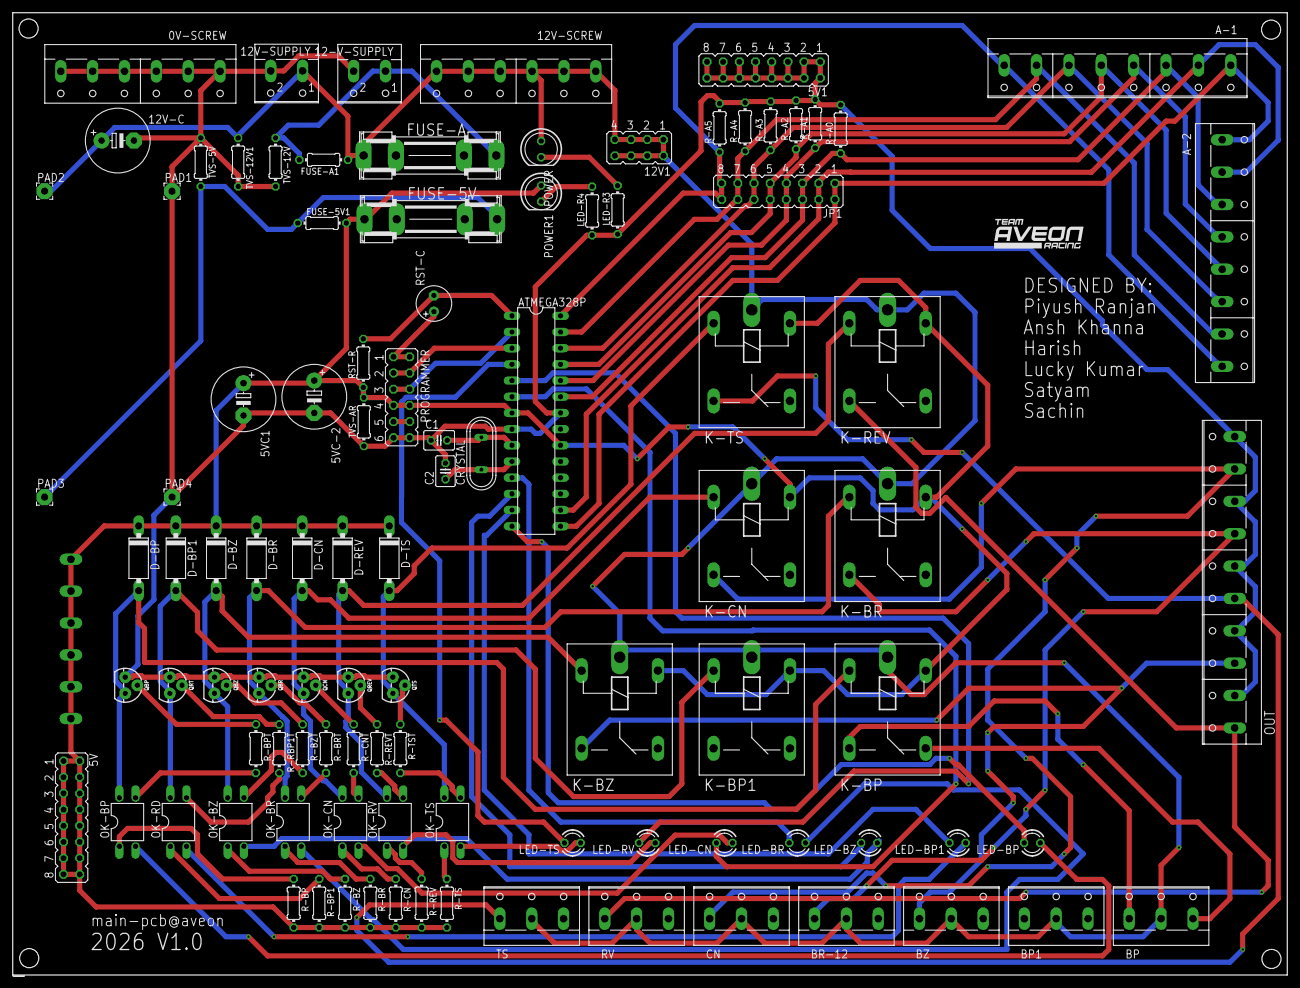
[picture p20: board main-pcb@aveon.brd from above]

Board: 2 copper layers, 200.0 x 151.0 mm, 100 parts (1 on the bottom side), 71 nets.

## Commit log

2026-01-20 Add files via upload
    image of board file made on eagle software
2026-07-13 Rename Screenshot 2026-01-20 130421.png to LV-VCU-PCB-brd-file-ss.png

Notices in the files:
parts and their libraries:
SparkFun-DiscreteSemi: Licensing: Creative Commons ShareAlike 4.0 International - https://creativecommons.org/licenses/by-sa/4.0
